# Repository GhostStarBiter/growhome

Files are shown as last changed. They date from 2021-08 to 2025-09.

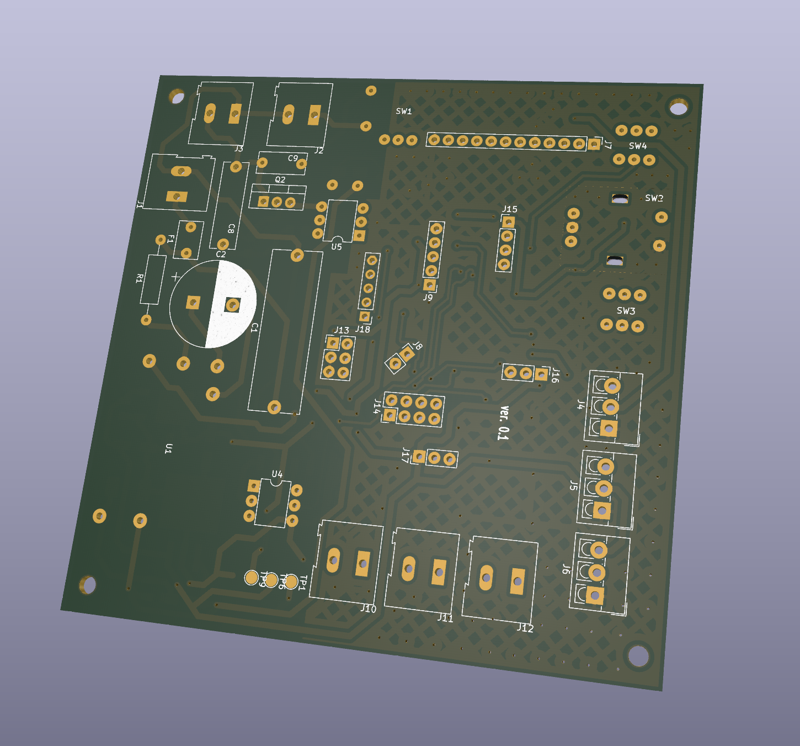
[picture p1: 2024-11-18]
documentation/pcb_design_images/pcb_top_3d.png

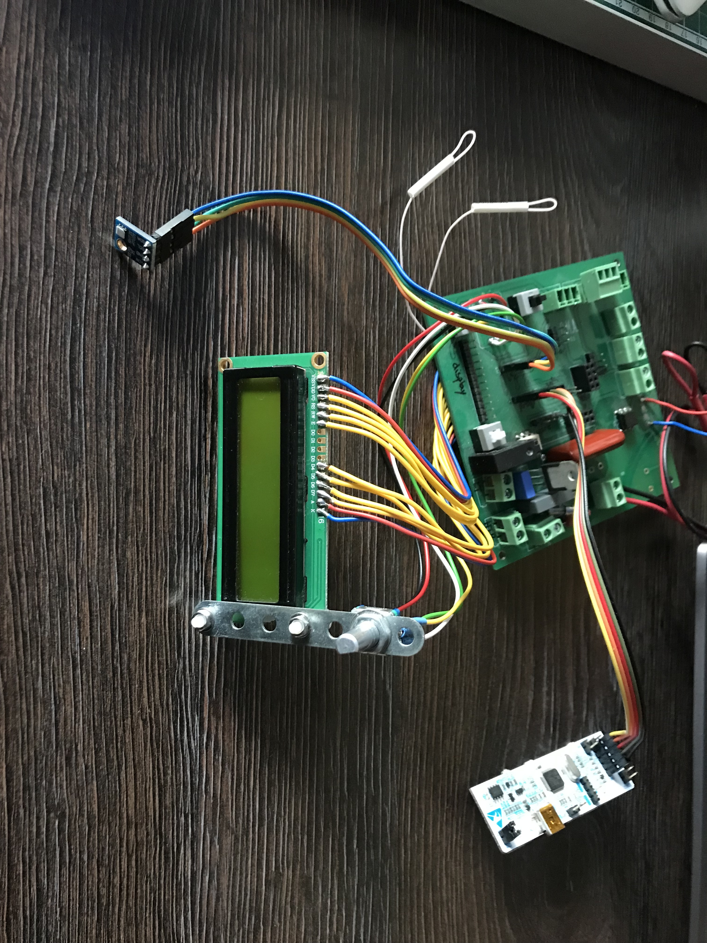
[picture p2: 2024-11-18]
documentation/assembled_photos/pcb_assembled_top.jpg

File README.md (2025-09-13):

# GreenHouse Project - Automated Embedded System

## Overview

This project is an **Automated Greenhouse System** designed for
sustainable indoor plant growth.\
It combines hardware, embedded software, and IoT connectivity to monitor
and control environmental conditions.

## Features

-   Automated light, temperature, and watering control.
-   Temperature & humidity monitoring.
-   Artificial grow lights with configurable schedules.
-   Irrigation & ventilation system.
-   Real-time monitoring via LCD and WiFi (ESP8266, WIP).
-   Data collection: temperature, humidity, water consumption, air
    exchange.

## Hardware

-   **Controllers:** STM32F103C8T6 + ESP8266 (WiFi, TBD).
-   **Sensors:** GY21 (I2C), OneWire temperature/humidity, analog water
    tank level sensor.
-   **Actuators:** LED grow lights, heater, water pump, fans (air income
    & mixing).
-   **User Interface:** LCD 2x16, rotary encoder with push-button,
    (planned web dashboard).
-   **Design Tools:** KiCad for schematics and PCB.

## Software

-   **IDE:** AC6 STM32 SystemWorkbench (Eclipse-based).
-   **Libraries:** STM32F10x SPL, FreeRTOS.
-   **Peripherals:** ADC+DMA, PWM timers, I2C+DMA, EXTI (encoder), UART,
    SPI.
-   **Tasks:**
    -   `service_task`: System heartbeat & cycle counter.
    -   `growbox_control_rtos_task`: Sensor reading,
        automatic/manual/remote control of lights, fans, heater, water
        pump.
    -   `system_user_interface_task`: LCD display, encoder interaction.
    -   `network_communication_task`: WiFi connectivity (ESP8266, TBD).

## Results

-   Successfully controls temperature, humidity, lighting, and watering
    cycles.
-   Reliable operation with modular tasks.
-   IoT features under development (remote monitoring & control).

## Future Work

-   Complete ESP8266 WiFi integration for IoT dashboard.
-   Add plant-specific grow plans with adaptive temperature control.
-   Expand to multi-node system for larger greenhouses.

## Author

**Dmytro Zelenets**

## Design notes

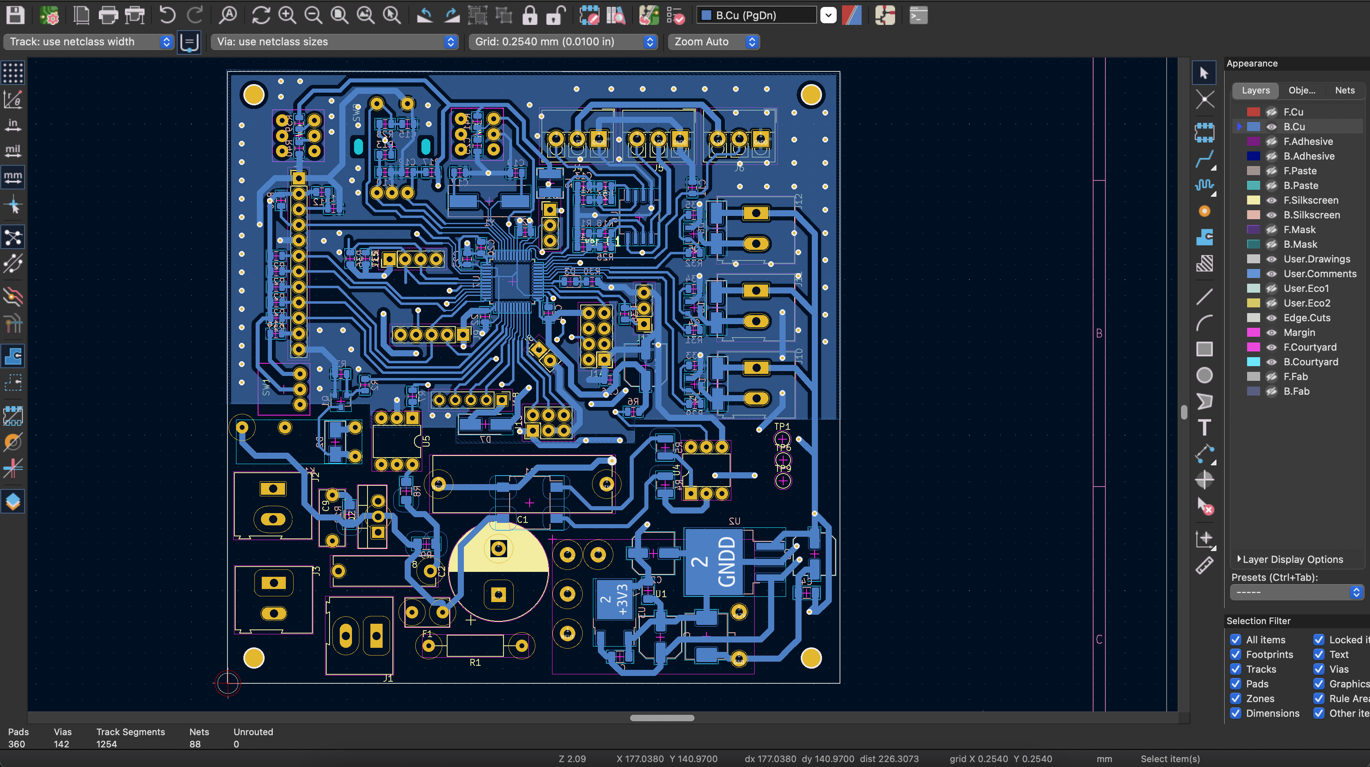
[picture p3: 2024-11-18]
documentation/pcb_design_images/pcb_bottom.png

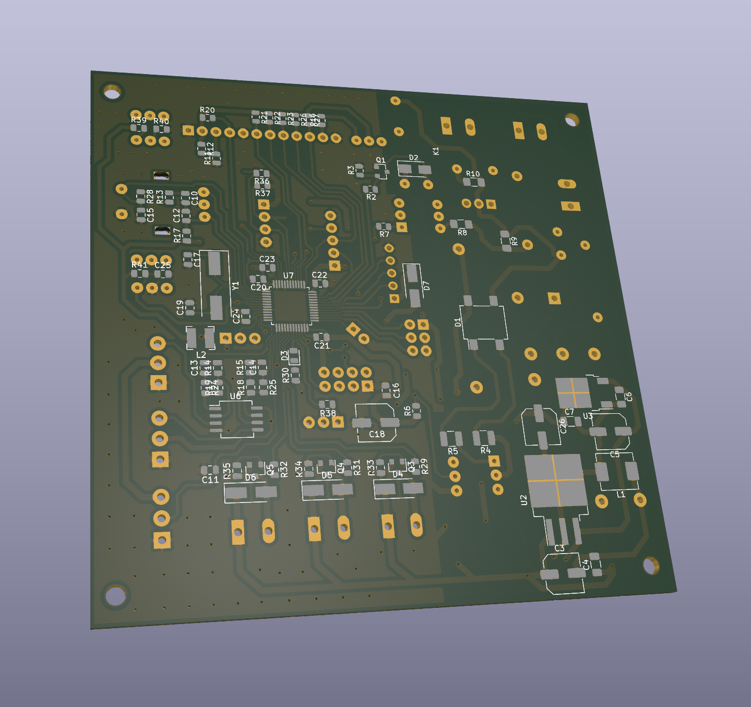
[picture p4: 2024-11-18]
documentation/pcb_design_images/pcb_bottom_3d.png

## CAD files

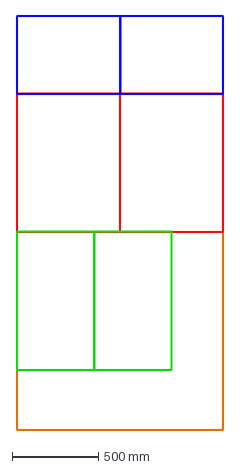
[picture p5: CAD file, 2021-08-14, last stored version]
documentation/construction/plywood_cut_2400x1200.dxf
1200.0 x 2400.0 mm

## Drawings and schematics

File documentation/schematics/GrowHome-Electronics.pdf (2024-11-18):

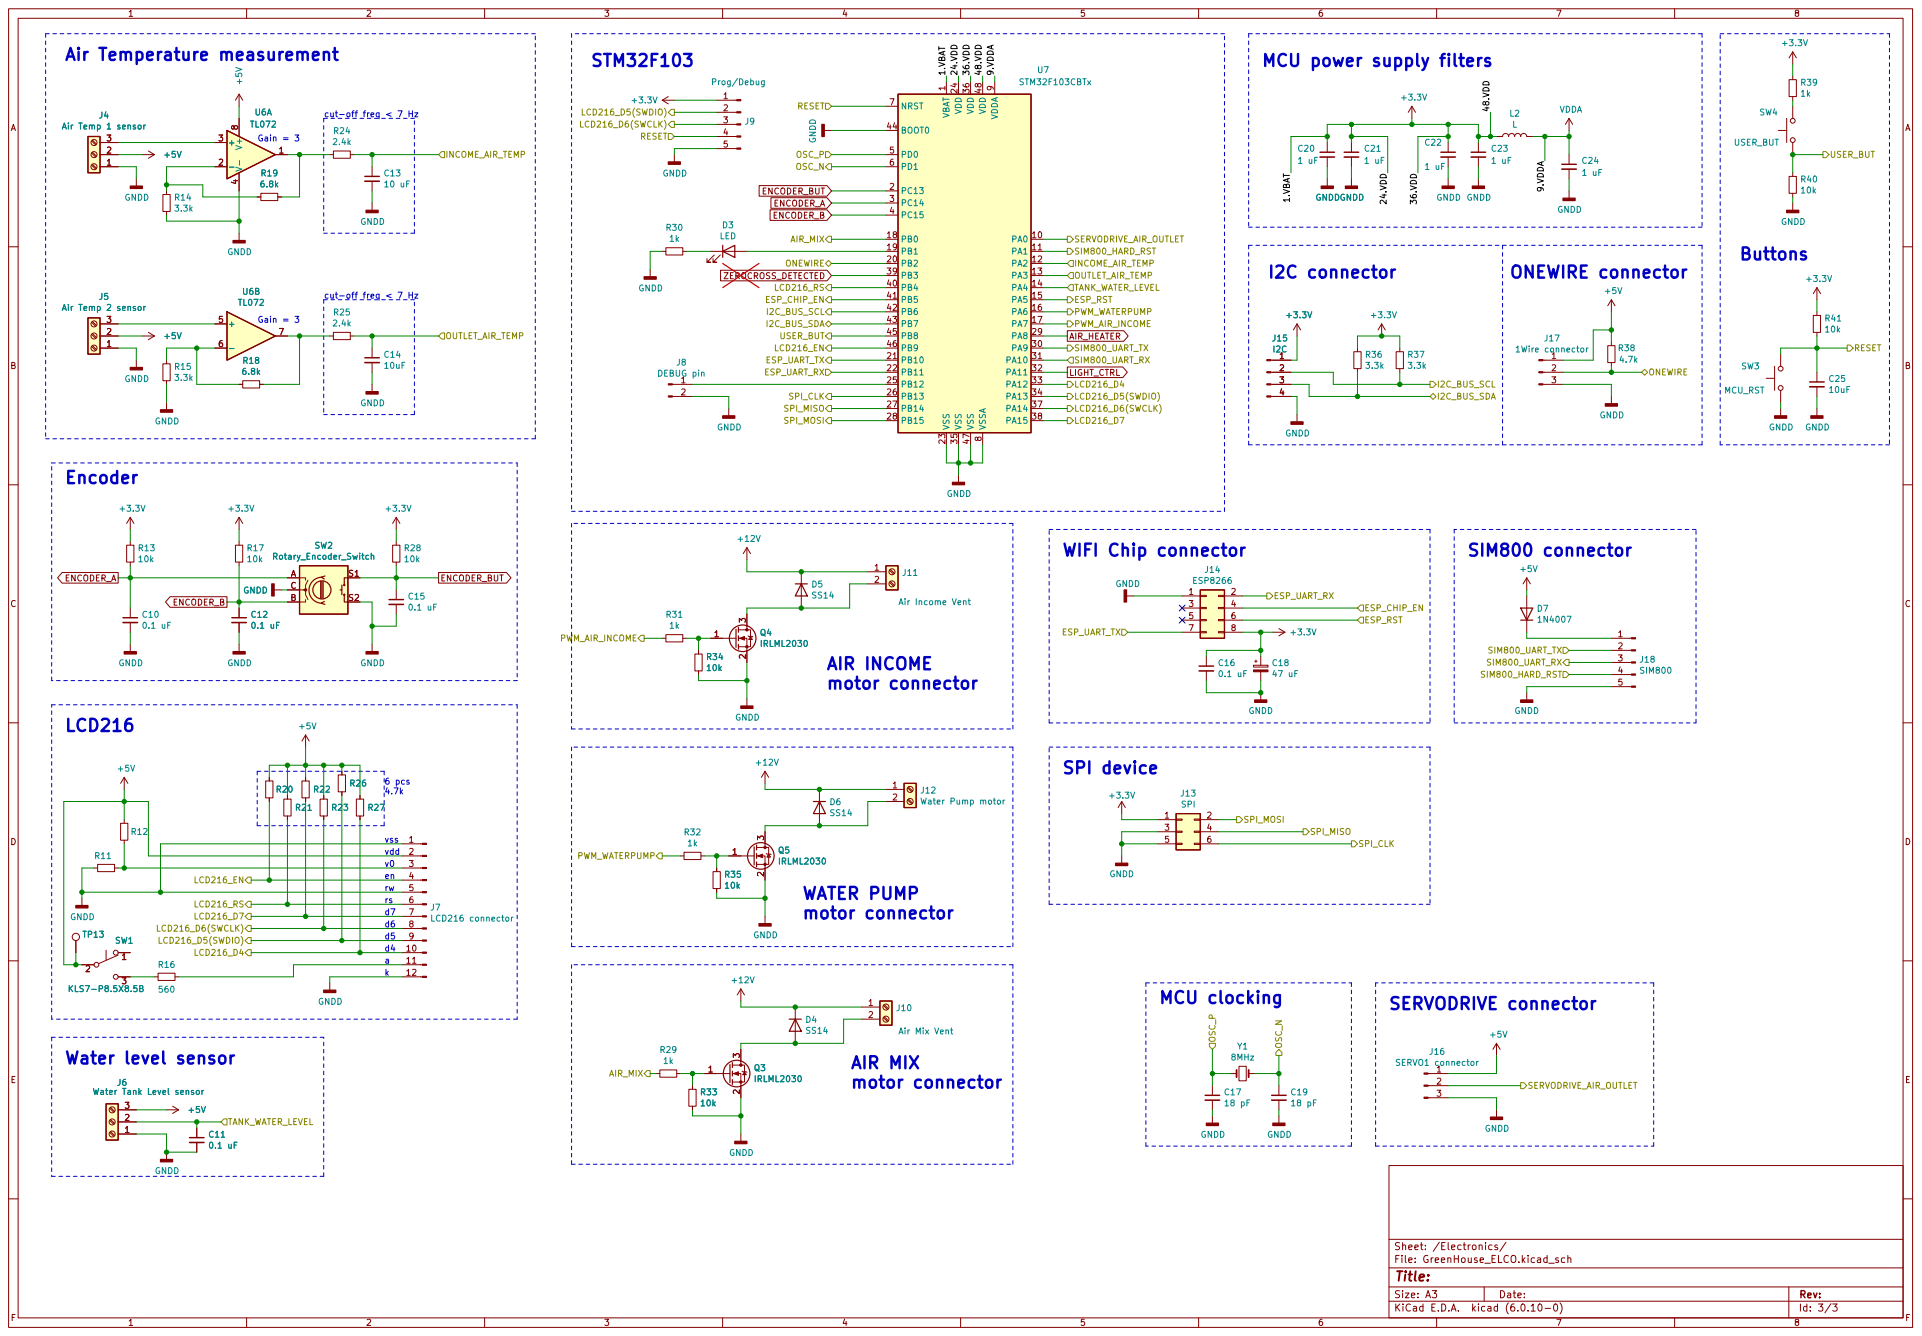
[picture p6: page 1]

1 PA0 10 PA1 11 PA2 12 PA3 13 PA4 14 PA5 15 PA6 16 PA7 17 PB0 18 PB1 19 PC13 2 PB2 20 PB10 21 PB11 22 VSS 23 VDD 24 PB12 25 PB13 26 PB14 27 PB15 28 PA8 29 PC14 3 PA9 30 PA10 31 PA11 32 PA12 33 PA13 34 VSS 35 VDD 36 PA14 37 PA15 38 PB3 39 PC15 4 PB4 40 PB5 41 PB6 42 PB7 43 BOOT0 44 PB8 45 PB9 46 VSS 47 VDD 48 PD0 5 PD1 6 NRST 7 VSSA

cut-off freq < 7 Hz

J6 Water Tank Level sensor

J6 Water Tank Level sensor 1

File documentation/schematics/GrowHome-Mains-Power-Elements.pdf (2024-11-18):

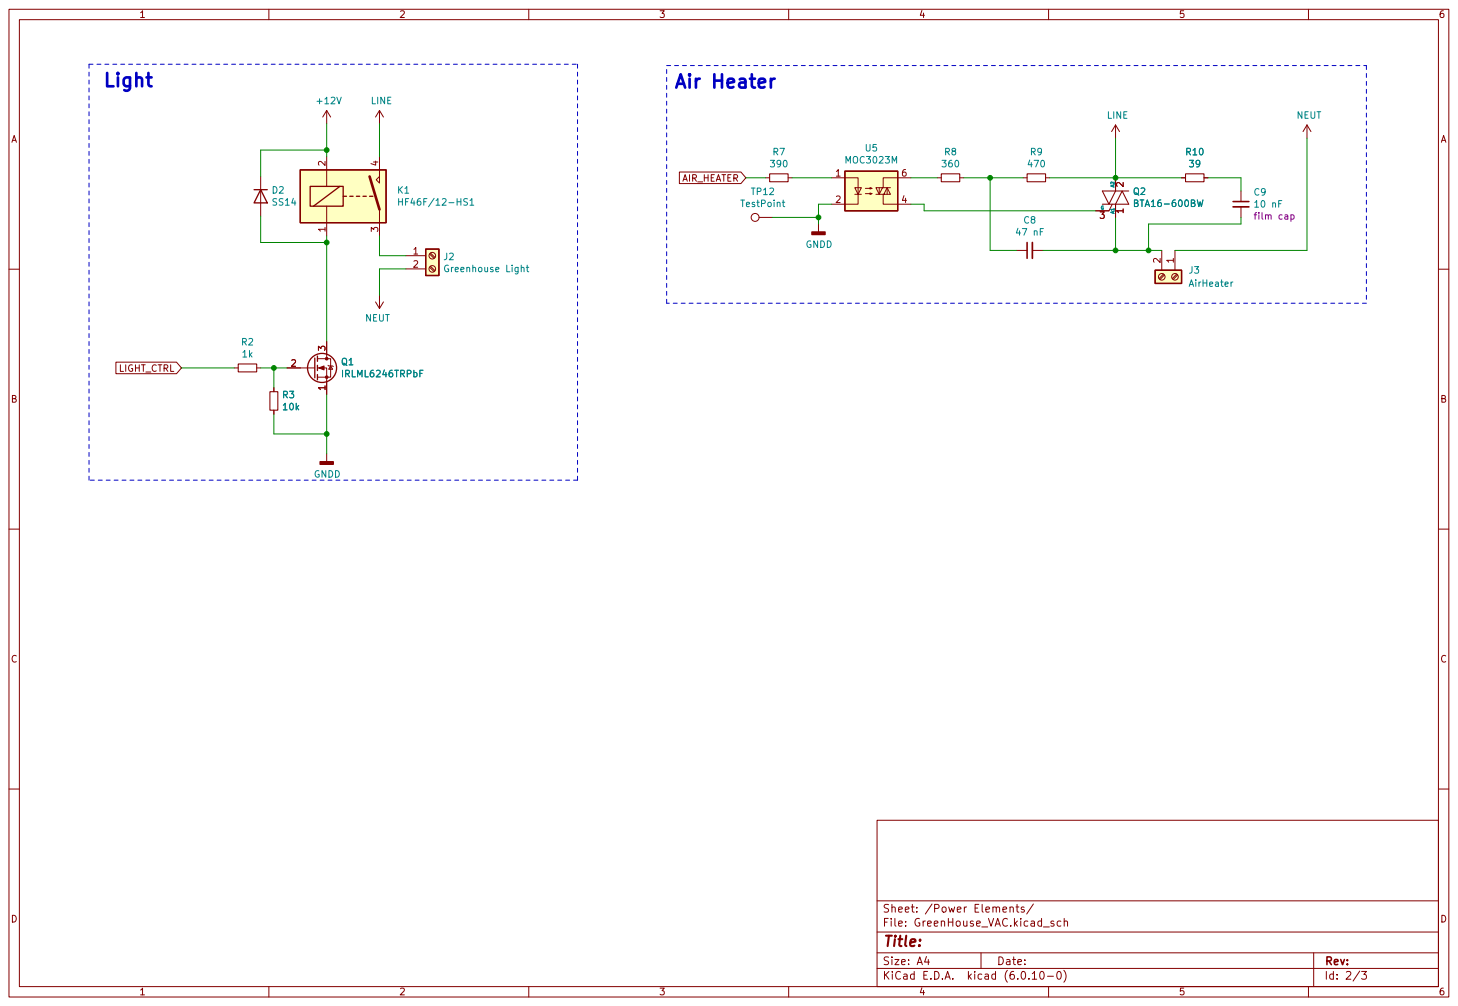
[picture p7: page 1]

File: GreenHouse_VAC.kicad_sch Sheet: /Power Elements/
Id: 2/3 Title:

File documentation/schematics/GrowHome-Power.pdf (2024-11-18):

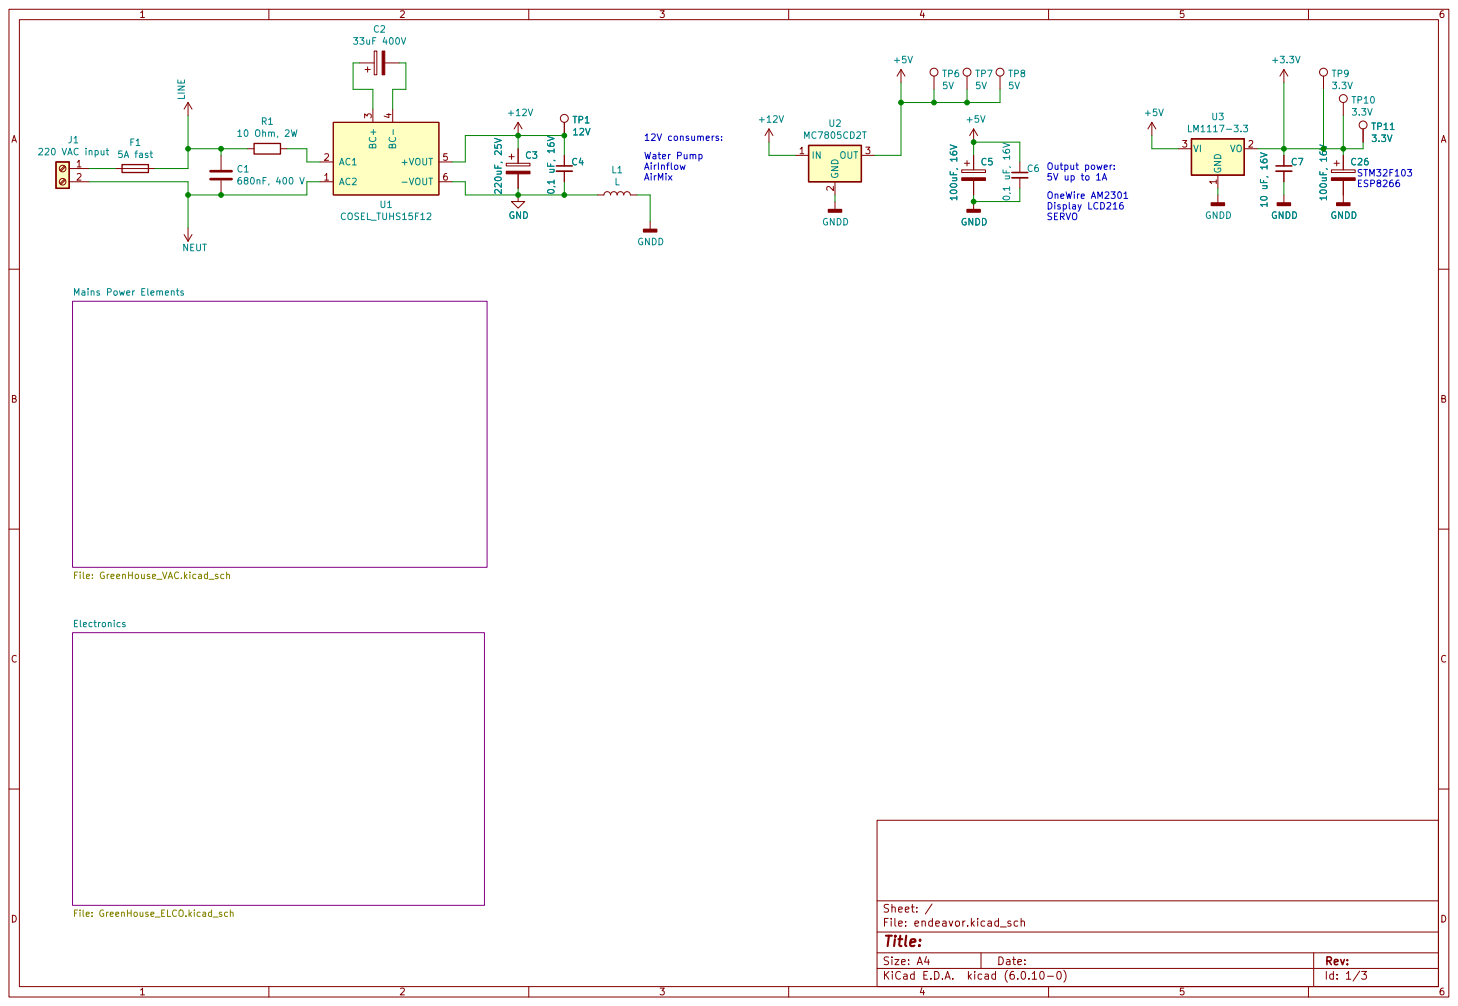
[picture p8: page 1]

5V up to 1A OneWire AM2301 Display LCD216 SERVO Water Pump AirInflow

File: endeavor.kicad_sch Sheet: / Electronics File: GreenHouse_ELCO.kicad_sch

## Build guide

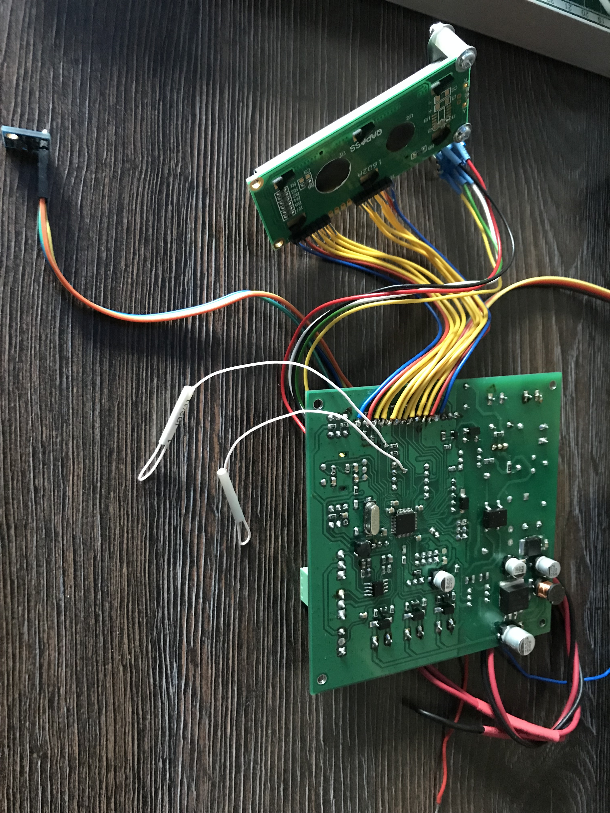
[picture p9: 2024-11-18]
documentation/assembled_photos/pcb_assembled_bottom.jpg

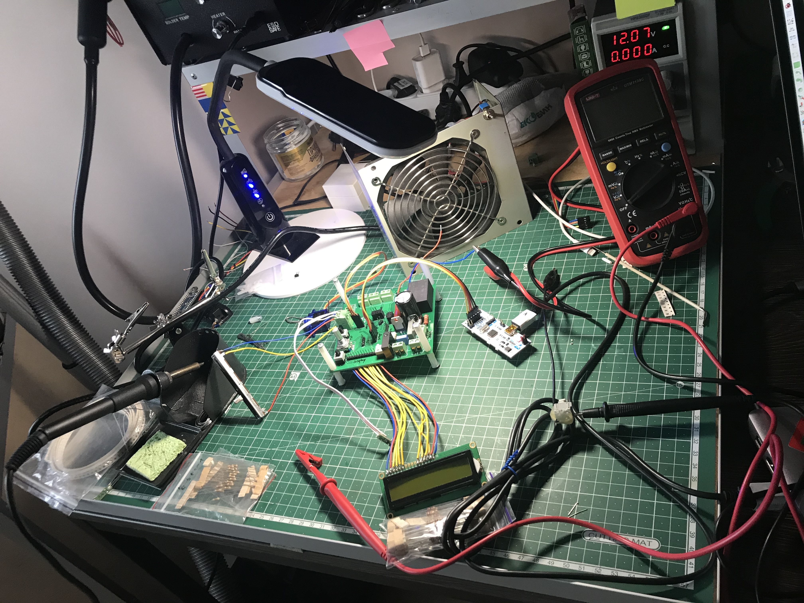
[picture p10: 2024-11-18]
documentation/assembled_photos/work_in_progress.jpg

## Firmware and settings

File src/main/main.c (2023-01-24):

#include <string.h>

// ***
#include "stm32f10x.h"
#include <system_config/FreeRTOSConfig.h>
#include "FreeRTOS.h"
#include "task.h"

// ***
#include "types.h"
#include "configuration/app_config.h"
#include "configuration/task_config.h"

// ***
#include "mcu_peripherals.h"

// ***
#include "system_user_interface/sui.h"

// ***
#include "green_house_system/green_house.h"

// ***
#if GRWHS_USE_NETWORK
#include "network/network.h"
#endif

//--------------------------------------------------------------------------------------------------
static void heartbeat_blink_led(void)
{
  static bool led_is_on = false;

  if(led_is_on)
  {
    led_is_on = false;
    mcu_gpio_set_led_status(DISABLE);
  }
  else
  {
    led_is_on = true;
    mcu_gpio_set_led_status(ENABLE);
  }

}


//--------------------------------------------------------------------------------------------------
static void service_task(void *pvParameters)
{
  const TickType_t  x_service_task_cycle_ms = SERVICE_TASK_CYCLE;
  TickType_t        x_last_wake_time          = xTaskGetTickCount();

  for(;;)
  {
    // ***
    vTaskDelayUntil(&x_last_wake_time, x_service_task_cycle_ms);

    // ***
    mcu_rtc_update();

    // ***
    heartbeat_blink_led();
  };
}


//_________________________________________________________________________________________________
int main(void)
{
  // ****
  mcu_init_peripherals();

  // ****
  xTaskCreate(  service_task,
                (const char *) "service_task",
                configMINIMAL_STACK_SIZE,
                NULL,
                (UBaseType_t) SERVICE_TASK_PRIORITY,
                ( xTaskHandle * ) NULL);

  // ****
  xTaskCreate(  growbox_control_rtos_task,
                (const char *) "growbox_task",
                configMINIMAL_STACK_SIZE,
                NULL,
                (UBaseType_t) GROWBOX_TASK_PRIORITY,
                ( xTaskHandle * ) NULL);

  // ****
  xTaskCreate(  system_user_interface_task,
                (const char *) "user_interface_task",
                configMINIMAL_STACK_SIZE,
                NULL,
                (UBaseType_t) USER_INTERFACE_TASK_PRIORITY,
                ( xTaskHandle * ) NULL);

#if GRWHS_USE_NETWORK
  // ****
  xTaskCreate(  network_communication_task,
                (const char *) "network_task",
                1024,
                NULL,
                (UBaseType_t) NETWORK_COMM_TASK_PRIORITY,
                ( xTaskHandle * ) NULL);
#endif

  // ****
  vTaskStartScheduler();
}

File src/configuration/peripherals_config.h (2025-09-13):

#ifndef PERIPHERALS_CONFIG_H
#define PERIPHERALS_CONFIG_H

#include "stm32f10x_gpio.h"
#include "stm32f10x_exti.h"

//          Servo motor
#define SERVO_GPIO_PORT                     GPIOA
#define SERVO_GPIO_PIN                      GPIO_Pin_0

#define SERVO_TIMER                         TIM2
#define SERVO_TIMER_PRESCALER               (36 - 1)                                // 1MHz = 1us tick
#define SERVO_TIMER_PERIOD                  20000                                   // 20 ms


//          ANALOG measurement
#define ANALOG_MEASURE_PORT                 GPIOA

// Air temperature 1 measurement pin
#define INCOME_AIR_TEMP_PIN                 GPIO_Pin_2

// Air temperature 2 measurement pin
#define OUTLET_AIR_TEMP_PIN                 GPIO_Pin_3

// Water tank 1 level measurement pin
#define WATER_TANK_LEVEL_MEASURE_PIN        GPIO_Pin_4


// ESP wifi module RST pin
#define ESP_RST_PORT                        GPIOA
#define ESP_RST_PIN                         GPIO_Pin_5



// PWM water pump (AF TIM3 CH1)
#define PWM_CONTROL_PORT                    GPIOA
#define PWM_WATER_PUMP_PIN                  GPIO_Pin_6
#define WATER_PUMP_CTRL_CHANNEL_FLAG        TIM_FLAG_CC1

//  PWM Air Input Green House (AF TIM3_CH2)
#define PWM_AIR_INPUT_PIN                   GPIO_Pin_7
#define AIR_INPUT_MOTOR_CHANNEL_FLAG        TIM_FLAG_CC2

#define PWM_CONTROL_TIMER                   TIM3
#define PWM_CONTROL_TIMER_PERIOD            1000
#define PWM_CONTROL_IRQHandler              TIM3_IRQHandler

// Triac control
#define TRIAC_GPIO_PORT                     GPIOA
#define TRIAC_AIR_HEATER_PIN                GPIO_Pin_8


//  SIM800 UART
#define SIM800_PORT                         GPIOA

#define SIM800_RESET                        GPIO_Pin_1

#define SIM800_UART_TX_PIN                  GPIO_Pin_9
#define SIM800_UART_RX_PIN                  GPIO_Pin_10
#define SIM800_UART_INTERFACE               USART1

// Green House Light
#define LIGHT_CTRL_PORT                     GPIOA
#define LIGHT_CTRL_PIN                      GPIO_Pin_11


//        LCD 2x16
// LCD216 D4 - Data 4 pin
#define LCD216_D4_PORT                      GPIOA
#define LCD216_D4_PIN                       GPIO_Pin_12

// LCD216 D5 - Data 5 pin
#define LCD216_D5_PORT                      GPIOA
#define LCD216_D5_PIN                       GPIO_Pin_13

// LCD216 D6 - Data 6 pin
#define LCD216_D6_PORT                      GPIOA
#define LCD216_D6_PIN                       GPIO_Pin_14

// LCD216 D7 - Data 7 pin
#define LCD216_D7_PORT                      GPIOA
#define LCD216_D7_PIN                       GPIO_Pin_15


// Air Income ventilator control status
#define MIX_AIR_PORT                        GPIOB
#define MIX_AIR_PIN                         GPIO_Pin_0

// LED status
#define SYSTEM_STATUS_LED_PORT              GPIOB
#define SYSTEM_STATUS_LED_PIN               GPIO_Pin_1

// ONEWIRE
#define ONEWIRE_PORT                        GPIOB
#define ONEWIRE_PIN                         GPIO_Pin_2

#define ONEWIRE_TIMER                       TIM4
#define ONEWIRE_TIMER_IRQn                  TIM4_IRQn
#define ONEWIRE_TIMER_IRQHandler            TIM4_IRQHandler

#define ONEWIRE_PIN_SOURCE                  GPIO_PinSource2
#define ONEWIRE_EXTI_LINE                   EXTI_Line2
#define ONEWIRE_EXTI_IRQn                   EXTI2_IRQn
#define ONEWIRE_EXTI_IRQHandler             EXTI2_IRQHandler

// LCD216 RS - Register select pin
#define LCD216_RS_PORT                      GPIOB
#define LCD216_RS_PIN                       GPIO_Pin_4

// ESP wifi chip Enable signal
#define ESP_EN_PORT                         GPIOB
#define ESP_EN_PIN                          GPIO_Pin_5

// I2C
#define I2C1_PORT                           GPIOB

#define I2C1_SCL_PIN                        GPIO_Pin_6
#define I2C1_SCL_PinSource                  GPIO_PinSource6

#define I2C1_SDA_PIN                        GPIO_Pin_7
#define I2C1_SDA_PinSource                  GPIO_PinSource7

#define I2C1_DMA_Channel                    DMA1_Channel7
#define I2C1_DMA_RX_IRQn                    DMA1_Channel7_IRQn
#define I2C1_DMA_RX_IRQHandler              DMA1_Channel7_IRQHandler

#define SYSTEM_BUTTON_PORT                  GPIOB
#define SYSTEM_BUTTON_PIN                   GPIO_Pin_8

// LCD216 E - Enable pin
#define LCD216_EN_PORT                      GPIOB
#define LCD216_EN_PIN                       GPIO_Pin_9

// ESP wifi chip communication interface
#define ESP_UART_PORT                       GPIOB

#define ESP_UART_TX_PIN                     GPIO_Pin_10
#define ESP_UART_RX_PIN                     GPIO_Pin_11

#define ESP_UART_IRQn                       USART3_IRQn
#define ESP_UART_DMA_IRQn                   DMA1_Channel2_IRQn
#define ESP_INTERFACE_IRQ_HANDLER           USART3_IRQHandler
#define ESP_UART_INTERFACE                  USART3
#define ESP_UART_DMA_TX_CHANNEL             DMA1_Channel2
#define ESP_UART_DMA_TX_COMPLETE            DMA1_FLAG_TC2
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

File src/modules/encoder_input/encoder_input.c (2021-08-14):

#include "stm32f10x.h"
#include "configuration/peripherals_config.h"

#include "encoder_input.h"

#define ENCODER_POS_MAX_TICKS               512                 // 1024 ticks - full range of output value
#define ENCODER_NEG_MAX_TICKS               (-512)

#define ENCODER_BUTTON_PRESSED              GPIO_ReadInputDataBit(ENCODER_BUTTON_PORT, ENCODER_BUTTON_PIN)
#define ENCODER_A_HIGH                      GPIO_ReadInputDataBit(ENCODER_A_PORT, ENCODER_A_PIN)
#define ENCODER_B_HIGH                      GPIO_ReadInputDataBit(ENCODER_B_PORT, ENCODER_B_PIN)

typedef struct{
  bool      button_activated;
  int16_t   ticks;
} encoder_input_t;

volatile encoder_input_t encoder;

//--------------------------------------------------------------------------------------------------
void encoder_init(void)
{
  encoder.button_activated  = false;
  encoder.ticks             = 0;
}


//--------------------------------------------------------------------------------------------------
int16_t encoder_get_ticks(void)
{
  return encoder.ticks;
}


//--------------------------------------------------------------------------------------------------
void encoder_reset_ticks(void)
{
  encoder.ticks = 0;
}


//--------------------------------------------------------------------------------------------------
void encoder_deactivate_button(void)
{
  encoder.button_activated = false;
}


//--------------------------------------------------------------------------------------------------
bool encoder_button_activated(void)
{
  return encoder.button_activated;
}


//--------------------------------------------------------------------------------------------------
void ENCODER_INPUT_IRQHandler(void)
{
  // *** BUTTON
  if(EXTI_GetITStatus(ENCODER_BUTTON_EXTI_LINE) != RESET && ENCODER_BUTTON_PRESSED)
  {
    if(!encoder.button_activated)
    {
      encoder.button_activated = true;
      encoder.ticks = 0;
    }
    else
    {
      encoder.button_activated = false;
      encoder.ticks = 0;
    }
    EXTI_ClearITPendingBit(ENCODER_BUTTON_EXTI_LINE);
  }

  // ENCODER
  if(EXTI_GetITStatus(ENCODER_A_EXTI_LINE) != RESET || EXTI_GetITStatus(ENCODER_B_EXTI_LINE) != RESET)
  {
    // *** "POSITIVE" rotation
    if(ENCODER_A_HIGH && !ENCODER_B_HIGH)
    {
      // check overflow
      if(encoder.ticks < ENCODER_POS_MAX_TICKS)
      {
        encoder.ticks++;
      }
    }

    // *** "NEGATIVE" rotation
    if(ENCODER_B_HIGH && !ENCODER_A_HIGH)
    {
      // check underflow
      if(encoder.ticks > ENCODER_NEG_MAX_TICKS)
      {
        encoder.ticks--;
      }
    }
    EXTI_ClearITPendingBit(ENCODER_A_EXTI_LINE);
    EXTI_ClearITPendingBit(ENCODER_B_EXTI_LINE);
  }
}

//  *** END OF FILE ***

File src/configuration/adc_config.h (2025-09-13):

#ifndef ADC_CONFIG_H
#define ADC_CONFIG_H

#define ADC_MAX_INPUT_VOLTAGE               3300  // mV
#define ADC_MAX_OUTPUT_RAW_VALUE            4095  // n/a

#define TEMP_1_CONVERSION_ORDER             1
#define CHANNEL_TEMP_1                      (TEMP_1_CONVERSION_ORDER - 1)
#define ANALOG_TEMP_1_CHANNEL               ADC_Channel_2

#define TEMP_2_CONVERSION_ORDER             2
#define CHANNEL_TEMP_2                      (TEMP_2_CONVERSION_ORDER - 1)
#define ANALOG_TEMP_2_CHANNEL               ADC_Channel_3

#define WATER_TANK_LEVEL_CONVERSION_ORDER   3
#define CHANNEL_WATER_TANK                  (WATER_TANK_LEVEL_CONVERSION_ORDER - 1)
#define WATER_TANK_LEVEL_CHANNEL            ADC_Channel_4

#define MEASUREMENTS_BUFFER_SIZE            8
#define WATER_TANK_LEVEL_MEAS_BUFF_SIZE     16

#define ADC_CONVERSION_CHANNELS             3

#define OPAMP_AMPLIFICATION_RATIO           3
#define LM_60_SW_AMPLIFICATION_RATIO        10
#define LM60_ZERO_DEGREES_OFFSET_CONVERTED  (424 * OPAMP_AMPLIFICATION_RATIO)
#define LM60_TEMP_SENSOR_OPAMP_MV_PER_DEG   (7*OPAMP_AMPLIFICATION_RATIO)
#define RAW_ADC_TO_MV(raw)                  (float) ((raw)*ADC_MAX_INPUT_VOLTAGE/ADC_MAX_OUTPUT_RAW_VALUE)

#endif // ADC_CONFIG_H

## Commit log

2021-01-23 System User Interface progress. Used buffer(2x16) for current display
    [growhome Debug.cfg]
2021-02-21 Started schedule. Started ESP-UART communicaiton
2021-03-06 Fixed bug of SERVO and ONEWIRE timer reinit
    [mcu_tim.c]
2021-03-06 Encoder module structure volatile
2021-03-08 Changed value of servo angles
2021-03-08 Added buffer cleanup every update call. Added disactivation of item on second button push
2021-03-10 Added set time from SUI. Changed behavior of MODE change. Fixed bug of Next-Hour
    [green_house.c]
2021-03-11 Implemented water pump power change
2021-06-28 Add PI regulation to temperature
2021-08-14 Pi ctrl.
    [plywood_cut_2400x1200.dxf]
2022-02-11 Change APP config
    - debug mode enabled;
    - changed default temperature;
    - changed temp regulation tolerance.
    [app_config.h]
2022-02-11 Change mean filter output to type double.
2022-02-12 Modify UART Transmit function.
2022-03-03 ADC config: changed mV per degree definition.
2022-03-03 WATER config: changed pump default power.
2022-03-03 GROWBOX: delete temperature states, changed temperature variable to double.
2022-03-03 SERVO: delete angle delta calculation.
2022-06-27 Commit after files transfer.
    [growhome Debug.cfg, plywood_cut_2400x1200.dxf]
2022-06-27 Implement GY21 sensor handling. Not tested.
2022-07-04 Enabled I2C1.
2022-07-04 GY21 sensor running DMA.
2022-09-28 Discover Idle time by DBG pin toggle.
2022-10-02 Fixed SUI bug of incorrect ticks value after button push, buffer garbage print.
2023-01-22 SPI configured
2023-01-24 Add missed MCU SPI configuration.
    [mcu_spi.c]
2024-11-18 Add schematics file, pdb design images and assembly photos.
2025-09-13 Built from makefile.
    [growhome Debug.cfg, plywood_cut_2400x1200.dxf]
